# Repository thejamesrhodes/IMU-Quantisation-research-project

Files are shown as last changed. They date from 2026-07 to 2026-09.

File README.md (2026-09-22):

# Sheppard MEMS Rate-Register Quantisation Research Project

Custom STM32F723 hardware, firmware and analysis for measuring output-register
quantisation noise in MEMS rate gyroscopes. Specifically gyroscopes that report an
angular-rate register rather than an integrated angle increment.








*This is a pre-publication research project. The preprint is not yet released.
the results, figures and numbers in this repository are working values and are subject to change. 
Nothing here has been peer-reviewed. Preliminary Datasets are available on Zenodo*

---

## Claim

Rate-register quantisation is predicted to appear at a $-1/2$ Allan-deviation
slope and to be absorbed silently into the fitted angle random walk (ARW),
rather than appearing as the $-1$-slope angle-quantisation ("Q") term of IEEE
Std 952, which describes a different output architecture for angle-increment
parts (FOGs, RLGs). This holds regardless of the error's statistics: whether the
quantisation error is PQN-white, deadbanded, or dithered, it enters the rate
and therefore appears inside the fitted ARW instead of appearing as a separable Q.

If that is correct, fitted stochastic-noise parameters depend on the
configuration (output data rate (ODR), full-scale range (FSR), output word
length) at which they were measured, and the $\sqrt{\text{ODR}}$
bandwidth-transfer rule embedded in every mainstream IMU calibration toolchain,
where it is stated as a condition requiring ideal decimation rather than a
validated result, has never been checked for modern high-ODR consumer parts.

**Why this has gone unnoticed.** The transfer rule was safe for the parts it was
developed on. An MPU-6050-class gyro (≈5 mdps/√Hz, 2011) at ±2000 dps / 100 Hz
sits at a dither ratio $\rho = \sigma/\Delta \approx 0.58$, where the
pseudo-quantisation-noise (PQN) model is valid to ~2 %. The ICM-42688-P
(≈2.8 mdps/√Hz, 2020) sits at $\rho \approx 0.32$, where it is not.

The board is named after W. F. Sheppard, whose 1898 paper gave the $-c^2/12$
correction for the variance of grouped data
([DOI](https://doi.org/10.1112/plms/s1-29.1.353)) - the same $\Delta^2/12$ the
whole experiment turns on. The correction reappears in an unexpected place: the
20-bit reference stream is itself a quantiser, and Sheppard's correction must be
applied to it before it can serve as a reference at all.

---

## Project Goals

- Test whether the fitted stochastic-noise parameters of a MEMS IMU transfer
  across ODR and FSR, and return a single configuration-invariant parameter set
  that does.
- Establish that rate-register quantisation presents at the $-1/2$ slope and is
  absorbed into the fitted ARW, distinct from the IEEE-952 angle-quantisation
  term.
- Derive the exact, parameter-free output-quantisation behaviour, governed by
  two quantities: the dither ratio $\rho = \sigma/\Delta$ and the sub-LSB bias
  phase $\mu \bmod \Delta$. Both measurable from a static code histogram with
  no additional hardware.
- Identify which requantisation architecture the output register implements
  (undithered/PQN, truncation, RPDF- or TPDF-dithered) from output data alone,
  validated against bit-exact software-dithered controls.
- Show that no mainstream toolchain (Kalibr, `allan_variance_ros`, …) models
  output-register quantisation or exposes $\rho$ or $\mu$, and document the
  effect size against configuration so a practitioner can locate their own.
- Publish the hardware, firmware, analysis code and a raw-integer-code,
  temperature-logged dataset. A dataset that, on the searches conducted, does
  not currently exist, because public IMU datasets are distributed as calibrated
  floats and the calibration destroys the code lattice.

---

## Project progress

| Item | Status |
| --- | --- |
| Data-logger PCB (4× IMU) Bring up | ✅ Complete |
| Firmware | ✅ Complete |
| Analysis chain ($\sigma$, $\rho$, $\mu$, $\varphi$, $\eta$; Allan; GMWM) | ✅ Complete |
| Exact $\eta(\rho,\varphi)$ theory, closed form | ✅ Validated |
| Primary curve $\eta(\rho)$ | ✅ Measured over a decade of $\rho$ |
| Experimental results vs exact theory | ✅ 0.4 % of range, no free parameters, both specimens |
| Relevance evidence (toolchain guidance, default ODR/FSR) | 🚧 In progress |
| Manuscript | 🚧 Skeleton, not in this repository |
| Preprint | ⏳ Not yet released |

---

## Hardware

| | |
| --- | --- |
| MCU | STM32F723ZET6, 32 MHz |
| Sensors | 2× ICM-42688-P, 1× ISM330DHCX, 1× BMI323, one SPI bus each |
| Storage | microSD on SDMMC2, exFAT |
| Host link | USB-C on OTG_HS, internal HS PHY |
| Power | 4S NiMH or USB-C |

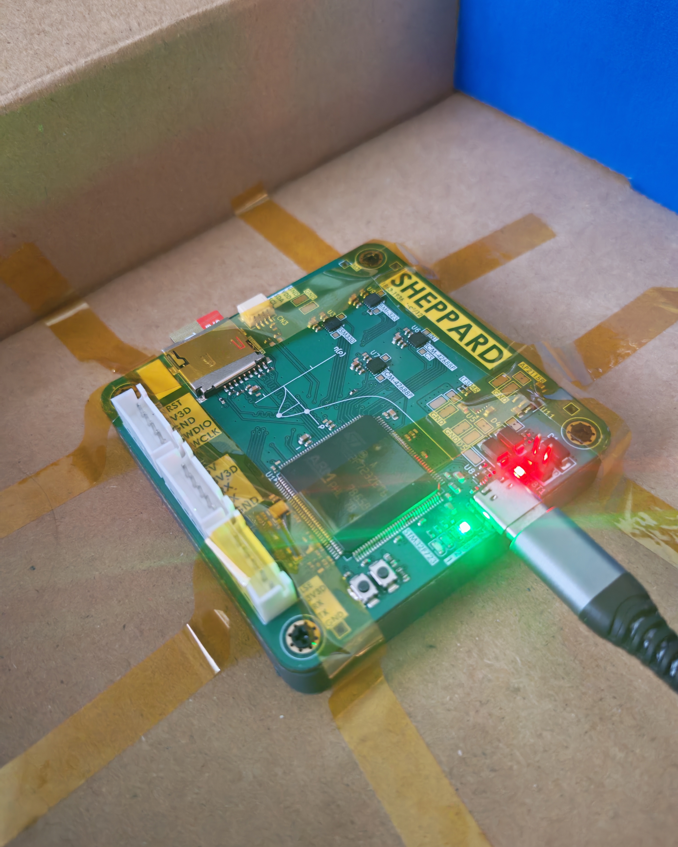
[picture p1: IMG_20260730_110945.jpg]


---

## Repository structure

```
GMWM Software/                 STM32CubeIDE firmware project + host Python
  Core/                          application sources
  tools/                         console, analysis, figures
GMWM Electronics/              KiCad 10 — data-logger PCB
Array Electronics ICM42688P/   KiCad 10 — ICM-42688-P board
Array Software ICM42688P/      firmware for the ICM-42688-P board
Test Datasets/                 records (gitignored; archived to Zenodo)
zenodo/                        dataset deposit build system
```

---

## Running it

```
pip install pyserial numpy matplotlib
python "GMWM Software/tools/sheppard_console.py"
```

The console is a GUI with five tabs: a terminal, the SD-card browser, the
campaign-plan editor, an analysis runner, and a figure viewer that renders the
plots in-app. It finds the board by USB ID rather than COM port and reconnects
on its own when the board resets.

Everything it does is also available from the command line, and the panel prints
the exact command before it runs it, so a result in the GUI and a result in a
terminal are the same result.

```
python analyse.py summary "../../Test Datasets" -o "../../Test Datasets/summary.csv" --fast
python figures.py "../../Test Datasets/summary.csv" -o "../../Figures"
python offset_fit.py "../../Test Datasets" --glob "*ph_k*.sdat"
```

---

## Flashing without an ST-LINK

The board reflashes itself over the same USB-C cable that carries the console.

Run `sheppard_selftest.py` once before trusting the flasher. It feeds the board
bad data five ways and checks each one is refused with flash untouched. Nothing
in it can erase the board.

SWD recovery is always there:

```
STM32_Programmer_CLI -c port=SWD mode=UR -e all -w "Debug/GMWM STM32.elf" -v -rst
```

---

## Status

94 records, two specimens, three axes. The register's architecture is identified
(truncation, bit-exact); $\eta(\rho)$ is measured over a decade of $\rho$; and a
controlled phase sweep tracks the exact theory to **0.4 % of its range with no
free parameters — on both specimens independently**. Repeatability is measured
at $\sigma_\eta = 0.0065$, so the theory is good to about twice the noise floor
of the apparatus.

The manuscript is a skeleton and is not held in this repository. The bench
work the preprint needs is
done; what remains is desk work — the relevance evidence, the software-dither
sweep, and the writing.

---

## Preprint and data

The preprint is not yet released. A manuscript is in preparation and is
intended for submission to a measurement-science journal (IOP
*Measurement Science and Technology*); this section will carry the preprint DOI
when it is public.

Campaign data is archived to Zenodo and is not held in this repository:

> Rhodes, J. (2026). *Paired 16-bit and 19-bit output records from two
> ICM-42688-P MEMS gyroscopes across output-rate and sub-LSB bias-offset
> sweeps* [Data set]. Zenodo. <https://doi.org/10.5281/zenodo.22860515>

---

## Conventions

SI units. LaTeX for maths. Campaign data goes to Zenodo with a DOI, not into
this repository.

The gyroscope's high-resolution FIFO field is 20 bits wide, of which 19 are
significant at ±2000 °/s full scale — the field's least significant bit is
always zero. All resolutions in this repository and in the dataset are quoted
on the 19-bit convention, so the reference lattice step is $\Delta' = \Delta/8$
and the register word is `gyro19 >> 3`.

---

## Licence

MIT — see `LICENSE`. The dataset is licensed separately under CC-BY-4.0.

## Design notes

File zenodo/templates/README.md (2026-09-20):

# Paired 16-bit and 19-bit output records from two ICM-42688-P MEMS gyroscopes across output-rate and sub-LSB bias-offset sweeps

Version {{VERSION}} · built {{BUILT}} · DOI {{DOI}}

{{N_RECORDS}} static-bench records from two ICM-42688-P MEMS gyroscopes (TDK
InvenSense). The sensors were stationary throughout: the board was clamped
and motionless, no rotation was applied, and no motion or attitude ground truth
is included.

Each record captures the device's 16-bit rate register alongside its extended
high-resolution output channel over the same physical samples, so the two
streams are digitisations of one shared input at resolutions differing by a
factor of eight. Samples are stored as raw integer codes with no scaling or
calibration applied, preserving the output code lattice that calibrated
floating-point datasets discard.

Totals: {{N_SAMPLES}} samples, {{HOURS}} hours, three axes per record.

---

## 1. Contents

| File | |
|---|---|
{{INVENTORY}}
| `summary.csv` | {{N_ROWS}} rows — one per record per axis. Configuration and moments only |
| `CODEBOOK.md` | column definitions, closed-form expressions for derived quantities |
| `read_sdat.py` | standalone reader and verifier; standard library + numpy |
| `MANIFEST-SHA256.txt` | SHA-256 of every file, and of every record inside every bundle |
| `LICENSE-DATA.txt` | CC-BY-4.0, covering the records and `summary.csv` |
| `LICENSE-CODE.txt` | MIT, covering `read_sdat.py` |

## 2. Quickstart

```bash
pip install numpy
unzip icm42688p-phase-sweep.zip -d records/

python read_sdat.py verify records              # CRC and continuity, per record
python read_sdat.py info   records/<one>.sdat  # header and achieved rate
python read_sdat.py rate   records/<one>.sdat  # board clock vs sensor clock
python read_sdat.py export records/<one>.sdat -o out.npz
```

`export` writes the decoded integer code arrays `gyro20`, `gyro16`, `accel20`,
`temp_raw`, `tmst_raw`, `tmst_us`, `block_index` and `block_t_us`, together with
`header_json`, so the exported file is self-describing. No scaling is applied.

### Physical units

Three things to get right before scaling the codes.

1. `gyro20` is a 20-bit field of which 19 bits are significant, so
   `sensor.hires_lsb_per_dps` applies to `gyro20 >> 1` and not to `gyro20`.
   Dividing `gyro20` by it directly gives a rate twice too large.
2. `sensor.gyro_lsb_per_dps` and `sensor.hires_lsb_per_dps` are rounded to
   three or four figures, which is a 0.1% scale error. `sensor.delta_mdps` is
   not rounded. Scale from it.
3. `tmst_us` is the sensor's own timestamp counter, which runs about 5% fast
   against the board's crystal-derived timer. Use `odr_measured_hz` from
   `summary.csv` as the sample rate; use `tmst_us` for ordering and gap
   detection only.

```python
import json, numpy as np

z = np.load("out.npz")
D = json.loads(str(z["header_json"]))["sensor"]["delta_mdps"] / 1000   # deg/s

reference_dps = (z["gyro20"] >> 1) * (D / 8)    # 19-bit channel
register_dps  =  z["gyro16"]       *  D         # 16-bit register
```

Both channels are the same physical samples at resolutions differing by a
factor of eight. Their means differ by roughly half a register LSB, which is
the truncation offset and not an error.

### If you only want the derived quantities

`summary.csv` is 47 kB and carries the per-record per-axis moments. The
expressions in `CODEBOOK.md` §3 turn those into sub-code phase, dither ratio,
added power and quantiser gain without downloading any records.

## 3. What is measured

| | |
|---|---|
| Part | ICM-42688-P (TDK InvenSense), two specimens, one SPI bus each |
| Full-scale range | ±2000 °/s — forced by the high-resolution mode |
| Register LSB | Δ = 61.035 m°/s |
| Reference lattice | Δ′ = Δ/8 = 7.629 m°/s |
| Output data rates | 25, 50, 100, 200, 500, 1000, 8000 Hz |
| Anti-alias filter | `585Hz_default` (87 records), `42Hz_floor` (7 records) |
| Logger | STM32F723ZET6, 32 MHz system clock, 8 MHz SPI, microSD |
| Supply | USB, all records |
| Motion | none — stationary, clamped, no applied rotation |
| Orientation | fixed for the whole campaign |

The system clock was held fixed and low across the campaign as an experimental
control so digital switching noise does not couple into the sensor and act as dither.

## 4. Word length and the 19-bit convention

The high-resolution FIFO field is 20 bits wide. Its least significant bit is
zero in all {{N_WORDS}} gyroscope words in this dataset, so 19 bits are
significant and the reachable lattice is Δ/8. Everything here is quoted on the
19-bit convention. The record headers carry `config.word_bits = 20`, which is
the field width, not the significant word length.

The register word is the reference word truncated by three bits,

```
gyro16 == gyro19 >> 3
```

which holds exactly in all {{N_WORDS}} words.

## 5. Characteristics a reuser should know

**Integrity.** All {{N_RECORDS}} records pass block-magic, sequence-continuity,
per-payload CRC-32, packet-header and timestamp-continuity checks. Zero FIFO
overflows and zero buffer-full events across the set.

A spectral line near 119 Hz is present in the records. Its origin has not
been identified. It aliases differently at each output rate, so it appears at a
different frequency and amplitude in each group. Measured, in units of Δ:

| Nominal ODR | Line frequency | Amplitude | Share of variance |
|---|---|---|---|
| 25 Hz | not detected | — | — |
| 50 Hz | 0–17.9 Hz | ≤ 0.07 Δ | 0–6 % |
| 100 Hz | 17.4–18.0 Hz | 0.18–0.24 Δ | 14–23 % |
| 200 Hz | 83.2–84.0 Hz | 0.06–0.76 Δ | 2–62 % |
| 500 Hz | 118.9–119.0 Hz | 0.83–1.15 Δ | 42–63 % |
| 1000 Hz | 118.4–119.4 Hz | 0.09–1.21 Δ | 5–52 % |
| 8000 Hz | 118.9–119.2 Hz | 0.84–1.21 Δ | 23–39 % |

Anyone treating these records as broadband noise should check the spectrum for
their rate first.

**Correlation between samples.** The anti-alias and user filter chains
correlate neighbouring samples at every rate. Estimators assuming independence
will be optimistic.

**Anti-alias filter records.** The seven `42Hz_floor` records vary the filter at
output rates of 50, 200 and 1000 Hz, each paired against default-filter records
at the same rate. Changing that filter also changes the line amplitude above and
the correlation between samples, so the setting is not a clean single-variable
axis. They are included for completeness.

**Temperature.** The die temperature is logged. `temp_span_mK` and
`temp_drift_mK` in `summary.csv` give the excursion and the end-to-end drift
per record; apply whatever criterion suits your purpose.

## 6. Record format

```
offset 0              4096 B  UTF-8 JSON header, space-padded
offset 4096 + 4096k           fixed 4 KiB blocks
  block                       32 B header + 4000 B payload + 64 B pad
```

Payload is the vendor's 20-byte FIFO Packet 4 verbatim (DS-000347 Rev. 1.6
§6.1), CRC-32 over every payload. The JSON header carries the firmware version
and build tag, board UID, clock tree, sensor part and slot, the full sensor
configuration and a verbatim readback of the configuration registers, so each
record is self-describing down to the register contents that produced it.

Filenames are `r<id>_<label>_<odr>.sdat`. `CODEBOOK.md` §4 maps labels to what
was varied.

## 7. Provenance

`summary.csv` is computed from the records in this deposit and from nothing
else. The bundled `read_sdat.py` is the reader used to produce it.

`MANIFEST-SHA256.txt` lists both the files as uploaded and each record inside
each bundle, so an unpacked archive can be checked record by record.

{{HEADER_NOTE}}

## 8. Citation

> Rhodes, J. ({{BUILT}}). *Paired 16-bit and 19-bit output records from two
> ICM-42688-P MEMS gyroscopes across output-rate and sub-LSB bias-offset
> sweeps* (Version {{VERSION}}) [Data set]. Zenodo.
> <https://doi.org/{{DOI}}>

## 9. Licence

Records and `summary.csv`: CC-BY-4.0 (`LICENSE-DATA.txt`).
`read_sdat.py`: MIT (`LICENSE-CODE.txt`).

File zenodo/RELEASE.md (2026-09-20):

# Release and deposit procedure

Version 1.0.0 is published: <https://doi.org/10.5281/zenodo.22860515>
(concept DOI, resolves to the newest version). What follows is the
procedure, and applies unchanged to the next version.

Two separate things, often confused:

| | Where it comes from | What it needs |
|---|---|---|
| **Data DOI** | a manual upload to Zenodo | nothing on GitHub at all |
| **Code DOI** | a GitHub release, archived automatically by Zenodo | a **public** repository |

The data deposit is §2–§4 and can be done today. The code DOI is §5 and is
blocked until §0 is resolved.

---

## 0. Read this first

**`.gitignore` stops future commits. It does not remove anything already in the
repository's history.** Seven commits in this repository add or modify the
technical notes, and the manuscript tree is tracked as well. Anyone with read
access can recover all of it with

```
git log --all --diff-filter=A --name-only
git show <commit>:<path>
```

Zenodo's GitHub integration [can only access public repositories][zgh]. So a
code DOI by that route means making this repository public, and making *this*
repository public publishes the history.

Three ways out, in the order I would consider them.

### A. Keep this repository private; upload the data deposit by hand

Nothing about history needs to change, because the data deposit never touches
GitHub. This is the whole of §2–§4 and it is sufficient for everything the
dataset is for — the DOI, the citation, the CV entry.

Cost: no code DOI yet. That can be added at any time, and adding it later does
not affect the data DOI.

### B. Publish a clean repository with no history

Export the working tree, drop the internal files, and initialise a new
repository from it. The current repository stays private and keeps being the
working one.

```powershell
cd "C:\"
git clone --depth 1 "file:///C:/IMU Research Project" IMU-release
cd IMU-release
Remove-Item -Recurse -Force .git
Remove-Item -Recurse -Force paper, Misc, "Test Datasets", Figures -EA SilentlyContinue
Remove-Item TN-*.md, SUPERSEDED.md, SESSION_HANDOVER.md, *_AUDIT_*.md, `
            Table_Verification_*.md, Concept_Note*.md, Preprint_Scaffold*.md, `
            DOCUMENTS_TO_ADD_TO_PROJECT.md, ZENODO_DEPOSIT_PLAN.md -EA SilentlyContinue
git init -b main
git add .
git commit -m "Initial public release: firmware, analysis tools, hardware, deposit build"
```

Then create an empty repository on GitHub and push to it. **Check the file list
before the first push** — once it is public, it is public:

```powershell
git ls-files | Select-String -Pattern "TN-|SUPERSEDED|AUDIT|Concept_Note|paper/|Test Datasets"
# expect: no output
```

### C. Rewrite this repository's history

`git filter-repo --path-glob 'TN-*.md' --invert-paths` and similar, then force
push. It works, but every existing clone and fork keeps the old objects, and if
the repository has ever been public you should assume the notes are already
copied. B is less work and has no failure mode.

**Check the current visibility before deciding.** GitHub → the repository →
Settings → General → Danger Zone shows whether it is public or private.

[zgh]: https://help.zenodo.org/docs/github/enable-repository/

### Before any of them: know what is in the source comments

The firmware and the analysis tools cite the project's own notes by number in
their comments. `.gitignore` does nothing about that, because the citations are
inside files that *should* be published.

```powershell
cd "C:\IMU Research Project\zenodo"
python check_public.py
python check_public.py --detail    # file:line for every hit
```

None of them disclose a result — they disclose that an internal numbering
scheme exists. Whether that is acceptable is a judgement. The script reports
and does not rewrite, because a blind regex pass over source comments is a good
way to damage working code for nothing. If you decide to strip them, do it in
the export of route B and keep the working tree intact.

The data deposit is unaffected either way: `build_deposit.py` scrubs the reader
it ships and fails the build if anything survives.

---

## 1. Untrack the internal files

Do this whichever route you take. It changes what future commits contain.

```powershell
cd "C:\IMU Research Project"
git rm -r --cached . --quiet
git add .
git status --short
```

`git status` should now show the internal files as deleted from the index while
they remain on disk. Confirm before committing:

```powershell
git status --short | Select-String -Pattern "^D " | Measure-Object
git ls-files | Select-String -Pattern "TN-|SUPERSEDED|AUDIT|paper/"   # expect none
git commit -m "Untrack internal notes, manuscript and generated figures"
```

---

## 2. Build the deposit

```powershell
cd "C:\IMU Research Project\zenodo"
python build_deposit.py --records "..\Test Datasets" --out build
```

The build refuses to finish if any record fails verification, if the 19-bit
relation does not hold in every word, or if any internal reference survives
into a deposit text file. Expected output: 11 files, about 100 MB.

To reserve the DOI first (§4 step 2) and have it appear inside the README,
codebook, licence and citation, rebuild with it:

```powershell
python build_deposit.py --records "..\Test Datasets" --out build `
                        --doi "10.5281/zenodo.22860516" --version 1.0.0
```

`--keep-gate-rule` ships the record headers exactly as logged, including the
internal name of the thermal criterion in `gate.rule`. Default is to normalise
it; see §3 of the deposit's own `README.md`.

---

## 3. Check it before uploading

```powershell
cd build
python read_sdat.py verify (Get-ChildItem -Recurse -Filter *.sdat).FullName
```

That needs the bundles unpacked first. The complete check, from an empty
directory, is the one that matters — it proves the deposit stands alone:

```powershell
$t = "$env:TEMP\deposit-check"
Remove-Item -Recurse -Force $t -EA SilentlyContinue
New-Item -ItemType Directory $t | Out-Null
Copy-Item build\* $t
cd $t
Get-ChildItem *.zip | ForEach-Object { Expand-Archive $_ -DestinationPath records -Force }
python read_sdat.py verify (Get-ChildItem records -Filter *.sdat).FullName | Select-String "^FAIL"
# expect: no output
```

Then confirm the manifest:

```powershell
Get-Content MANIFEST-SHA256.txt |
  Where-Object { $_ -match "^[0-9a-f]{64}  \w[-\w]*\.zip::" } |
  ForEach-Object {
    $h, $n = $_ -split "  ", 2
    $f = "records\" + ($n -split "::")[1]
    if ((Get-FileHash $f -Algorithm SHA256).Hash -ne $h.ToUpper()) { "MISMATCH $f" }
  }
# expect: no output
```

---

## 4. Upload to Zenodo

1. Sign in at <https://zenodo.org>. Add an ORCID first if you do not have one —
   it takes ten minutes, it is free, and a deposit without one is materially
   weaker. Link it under Profile → Linked accounts.

2. **New upload** → **Get a DOI now!** to reserve the DOI. Do not delete the
   draft afterwards; the reservation is lost with it.

3. Rebuild with the reserved DOI (§2) so it appears in the README, codebook and
   citation, then upload all 11 files from `build\`.

4. Metadata:

   | Field | Value |
   |---|---|
   | Resource type | Dataset |
   | Title | Paired 16-bit and 19-bit output records from two ICM-42688-P MEMS gyroscopes across output-rate and sub-LSB bias-offset sweeps |
   | Creators | Rhodes, James — *Independent Researcher* — ORCID 0009-0000-9893-145X |
   | Description, copyright, references, keywords | see `ZENODO_METADATA.md`, paste-ready |
   | Licences | Creative Commons Attribution 4.0 International **and** MIT |
   | Version | 1.0.0 |
   | Language | English |
   | Keywords | MEMS gyroscope; quantisation noise; Allan variance; angle random walk; inertial sensor calibration; ICM-42688-P; truncating quantiser; sensor characterisation |

   Leave *Related identifiers* empty for now. Metadata stays editable forever,
   so the manuscript link can be added when there is one.

5. **Preview**, read it as a stranger, then **Publish**.

**Files are editable for 45 days after publishing. Metadata is editable
indefinitely.** So a metadata gap is cheap and a file mistake is not. After 45
days a file change means a new version with its own DOI.

---

## 5. Code DOI, later

Only after §0 is resolved and a public repository exists.

1. Zenodo → Profile → Linked accounts → connect GitHub.
2. Zenodo → GitHub → toggle the repository **On**.
3. On GitHub, draft a release and tag it:

```powershell
git tag -a v1.0.0 -m "Firmware, analysis tools and hardware as used for the dataset"
git push origin v1.0.0
```

4. Publish the release on GitHub. Zenodo ingests it and issues a DOI.
5. Edit the **data** deposit's metadata and add the code DOI under
   *Related identifiers* → `isSupplementedBy`. Add the reverse link on the code
   record.

---

## 6. After publishing

- Put the **concept** DOI on the CV and in the manuscript, not the version DOI.
  The concept DOI always resolves to the newest version; the version DOI pins
  one release.
- Fill the manuscript's data-availability statement with the concept DOI and
  the repository URL.
- New records later — the remaining run plan, a second campaign — are a **new
  version** of the same deposit, not a new record. Rebuild with
  `--version 1.1.0` and use *New version* on the Zenodo record.

---

## What the build produces

| File | |
|---|---|
| `sheppard-phase-sweep.zip` | 50 records |
| `sheppard-odr-sweep.zip` | 14 records |
| `sheppard-offset-calibration.zip` | 22 records |
| `sheppard-aaf-variation.zip` | 8 records |
| `summary.csv` | 282 rows, 22 columns |
| `read_sdat.py` | standalone reader |
| `CODEBOOK.md` | column definitions and derived quantities |
| `README.md` | deposit-level documentation |
| `MANIFEST-SHA256.txt` | hashes, including per-record inside each bundle |
| `LICENSE-DATA.txt` | CC-BY-4.0 |
| `LICENSE-CODE.txt` | MIT |

11 files, about 100 MB. Zenodo allows 100 files and 50 GB per record.

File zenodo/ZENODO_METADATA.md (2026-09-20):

# Zenodo metadata — paste-ready

DOI reserved: **10.5281/zenodo.22860516**

Everything below goes into the Zenodo deposit form. Fields marked **required**
are the ones with a red star.

---

## Resource type **required**

`Dataset`

---

## Title **required**

```
Paired 16-bit and 19-bit output records from two ICM-42688-P MEMS gyroscopes across output-rate and sub-LSB bias-offset sweeps
```

17 words, 124 characters.

---

## Creators **required**

| Field | Value |
|---|---|
| Family name | `Rhodes` |
| Given names | `James` |
| Identifier | your ORCID |
| Affiliation | `Independent researcher` |
| Role | leave blank |

---

## Publication date **required**

Today's date. Zenodo prefills it.

---

## Description **required**

Zenodo's description box is rich text. Paste this. 279 words, inside the 120-280
typical of Zenodo dataset records.

```
This dataset contains 94 static-bench records from two ICM-42688-P MEMS
gyroscopes (TDK InvenSense). The sensors were stationary throughout: the board
was clamped and motionless, no rotation was applied, and no motion or attitude
ground truth is included.

Each record captures the device's 16-bit rate register alongside its extended
high-resolution output channel over the same physical samples, so the two
streams are digitisations of one shared input at resolutions differing by a
factor of eight. Samples are stored as raw integer codes, with no scaling or
calibration applied, preserving the output code lattice that calibrated
floating-point datasets discard. Totals: 10,599,722 samples, 9.43 hours, three
axes per record.

Two quantities were varied, on independent axes rather than as a grid: the
output data rate (25 Hz to 8 kHz), and the device's user-offset trim register,
which moves the sensor bias within a single output code.

Contents: four record bundles (offset sweep, output-rate sweep, trim-register
calibration, anti-alias filter variation); summary.csv, giving per-record
per-axis configuration and moments; a standalone Python reader and verifier; a
codebook defining every column and giving closed-form expressions for derived
quantities; and a SHA-256 manifest.

Format: each record carries a 4 KiB JSON header with firmware version, clock
and sensor configuration and a verbatim configuration-register readback,
followed by 4 KiB data blocks holding the vendor's FIFO packets with CRC-32
over every payload. All 94 records pass integrity verification.

Notes: a spectral line near 119 Hz is present and aliases to a different
frequency at each output rate; measured amplitudes are tabulated in README.md.
The filter chains correlate neighbouring samples at every rate. Die
temperature is logged per record.

Licence: records and summary.csv are CC-BY-4.0; the bundled reader is MIT.
```

---

## Licences **required** — add both

Zenodo supports several licences on one record, and documents exactly this case
("software under the MIT license, but documentation under CC-BY"). This deposit
is mixed, so declare both rather than picking one:

| Licence | Covers |
|---|---|
| `Creative Commons Attribution 4.0 International` | the record bundles and `summary.csv` |
| `MIT License` | `read_sdat.py` |

CC-BY-4.0 is Zenodo's default and is already selected. Click **Edit** beside it
to confirm, then **Add standard** and search `MIT` for the second. Zenodo uses
the SPDX list, so the entries are `cc-by-4.0` and `mit`.

Watch for near-identical entries in the picker — several Creative Commons
variants differ only by version or by `-NC` / `-SA` suffixes.

---

## Copyright

Optional free-text field, separate from the licence. It names the rights
holder; the licence says what others may do. Worth filling here precisely
because the deposit is mixed-licence — one unambiguous statement of who holds
the rights removes any question about which file belongs to whom.

```
Copyright (c) 2026 James Rhodes. Records and summary.csv licensed CC-BY-4.0; read_sdat.py licensed MIT.
```

---

## References

Optional list of free-text references, rendered as a References block on the
record page. Add one per entry.

These are exactly the five cited in `CODEBOOK.md` — the datasheet defines the
packet structure and register names, and the other four define the quantiser
relations used in §3. Nothing is listed that the deposit does not use. All
DOIs verified against Crossref.

```
TDK InvenSense (2020). ICM-42688-P Datasheet, DS-000347 Rev. 1.6.
```

```
Sheppard, W. F. (1898). On the Calculation of the most Probable Values of Frequency-Constants, for Data arranged according to Equidistant Divisions of a Scale. Proceedings of the London Mathematical Society, s1-29, 353-380. https://doi.org/10.1112/plms/s1-29.1.353
```

```
Sripad, A., & Snyder, D. (1977). A Necessary and Sufficient Condition for Quantization Errors to be Uniform and White. IEEE Transactions on Acoustics, Speech, and Signal Processing, 25(5), 442-448. https://doi.org/10.1109/TASSP.1977.1162977
```

```
Widrow, B., & Kollar, I. (2008). Quantization Noise: Roundoff Error in Digital Computation, Signal Processing, Control, and Communications. Cambridge University Press. https://doi.org/10.1017/CBO9780511754661
```

```
Vardeman, S. B. (2005). Sheppard's Correction for Variances and the "Quantization Noise Model". IEEE Transactions on Instrumentation and Measurement, 54(5), 2117-2119. https://doi.org/10.1109/TIM.2005.853348
```

**Not included: IEEE Std 952.** It was in an earlier draft of the codebook and
is now removed from both. It specifies test procedures for interferometric
fibre-optic gyroscopes — a different output architecture from the part in this
dataset — and nothing in the deposit uses it. Listing it would suggest the
records relate to that standard.

---

## Version

```
1.0.0
```

---

## Language

```
English
```

---

## Keywords

Data-descriptive terms first, so the deposit is findable by people who are not
already thinking about quantisation. Add one at a time:

```
MEMS gyroscope
inertial measurement unit
raw sensor data
uncalibrated data
static bench measurement
ICM-42688-P
sensor characterisation
Allan variance
output data rate
quantisation noise
angle random walk
truncating quantiser
```

---

## Related works

Leave empty for now. Metadata stays editable indefinitely, so the manuscript
and the code repository go in later:

| Relation | Identifier | Resource type |
|---|---|---|
| `is supplemented by` | repository URL | Software |
| `is supplement to` | manuscript DOI, once it has one | Publication |

---

## Files

All eleven files from `zenodo\build\`:

```
CODEBOOK.md
LICENSE-CODE.txt
LICENSE-DATA.txt
MANIFEST-SHA256.txt
README.md
icm42688p-aaf-variation.zip
icm42688p-odr-sweep.zip
icm42688p-offset-calibration.zip
icm42688p-phase-sweep.zip
read_sdat.py
summary.csv
```

Set the default preview file to `README.md` if Zenodo offers the choice.

---

## Visibility

`Public`. Do not tick "Apply an embargo".

---

## Citation this produces

> Rhodes, J. (2026). *Paired 16-bit and 19-bit output records from two
> ICM-42688-P MEMS gyroscopes across output-rate and sub-LSB bias-offset
> sweeps* (Version 1.0.0) [Data set]. Zenodo.
> <https://doi.org/10.5281/zenodo.22860516>

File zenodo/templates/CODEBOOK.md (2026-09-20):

# Codebook

Version {{VERSION}} · built {{BUILT}} · DOI {{DOI}}

`summary.csv` has {{N_ROWS}} rows, one per record per gyroscope axis, and
{{N_RECORDS}} distinct records, all taken with the sensors stationary. Every
column is either configuration read from the record header or a moment computed
from that record's own samples. No column is fitted, corrected toward a model,
or compared against a prediction.

Quantities derived from these columns are given in §3 as explicit expressions,
so that a reader applies them rather than inheriting them.

Formulas are written in plain text and are directly usable in Python or any
spreadsheet. `mod` is the non-negative remainder, `sqrt` the square root,
`floor` rounding toward negative infinity, and `^` exponentiation.

---

## 1. Conventions

| Symbol | Definition | Value |
|---|---|---|
| Δ | 16-bit rate-register LSB | 61.035 m°/s at ±2000 °/s |
| Δ′ | reference-lattice step | Δ/8 = 7.629 m°/s |
| v | continuous rate at the quantiser input | — |
| x | reference stream, 19-bit | in units of Δ |
| Q | register stream, 16-bit | in units of Δ |
| φ | sub-code bias phase | in units of Δ |
| ρ | dither ratio | dimensionless |
| η | normalised added power | dimensionless |
| G | quantiser gain | dimensionless |

All `*_lsb` and `*_lsb2` columns are in units of Δ and Δ² respectively. To
convert to physical units multiply by Δ or Δ²; `sensor.delta_mdps` in each
record header carries the value that record was taken at.

**Word length.** The device's high-resolution FIFO field is 20 bits wide. The
field's least significant bit is zero in all {{N_WORDS}} gyroscope words in this
dataset, so 19 bits are significant and the reachable lattice is Δ/8. All
resolutions here are quoted on the 19-bit convention:

```
x  = Δ' * gyro19          with Δ' = Δ/8
gyro16 = gyro19 >> 3
```

The second identity holds bit-exactly in all {{N_WORDS}} words, so the register
is a truncation of the reference and not a rounding of it:

```
Q(v) = Δ * floor(v / Δ)
```

**Phase reference.** φ is edge-referenced: φ = 0 at a code boundary,
φ = 0.5 at mid-code.

**Detrending.** Every moment column is computed on the record after removal of
a least-squares straight line, so that bench temperature drift during a record
does not enter the variance. The first-moment column `mean_ref_lsb` is computed
on the undetrended stream.

---

## 2. Columns

### 2.1 Identity

| Column | Definition |
|---|---|
| `file` | record filename |
| `label` | run label from the record header |
| `specimen` | sensor slot, 1 or 2; distinct physical parts of the same type |
| `axis` | `X`, `Y` or `Z` |

### 2.2 Configuration, read verbatim from the record header

| Column | Definition | Units |
|---|---|---|
| `odr_nominal_hz` | commanded output data rate | Hz |
| `odr_measured_hz` | rate measured by the logger's own timer over the record | Hz |
| `aaf` | anti-alias filter setting | — |
| `offset_user_steps` | value written to the device's user-offset trim register | steps |
| `power` | supply during the record | — |

### 2.3 Extent and integrity

| Column | Definition |
|---|---|
| `n_samples` | FIFO samples in the record |
| `minutes` | `n_samples / odr_measured_hz / 60` |
| `verify` | `ok` if block magic, sequence continuity, CRC-32 over every payload, packet-header sanity and timestamp continuity all pass |
| `fifo_overflows` | device-reported FIFO overflow count |
| `ring_full` | logger-reported buffer-full count |
| `temp_span_mK` | `1000 * (max(T) - min(T))` over the record, from the device's own die sensor |
| `temp_drift_mK` | `1000 * abs(mean(T, last 5%) - mean(T, first 5%))` |

`verify` is `ok` for every row in this release.

### 2.4 Moments

`Var` and `Cov` are sample estimators with denominator `n - 1`. A tilde denotes
the detrended stream.

| Column | Definition |
|---|---|
| `mean_ref_lsb` | `mean(x)`, undetrended |
| `var_ref_lsb2` | `Var(x~)` |
| `var_reg_lsb2` | `Var(Q~)` |
| `cov_lsb2` | `Cov(Q~, x~)` |

### 2.5 Descriptive

| Column | Definition |
|---|---|
| `tail_ratio` | `std(x~) / (1.4826 * MAD(x~))`. The constant is the Gaussian consistency factor. Values materially above 1 indicate the tails carry disproportionate weight — a transient during the record rather than wide noise. |
| `n_codes` | distinct 16-bit register codes occupied by the axis over the record |

---

## 3. Derived quantities

Each expression is exact given the definitions in §1 and the model of the
reference channel in §3.1. Nine significant figures are carried in the moment
columns so that these reproduce to more places than are useful.

### 3.1 The reference channel is itself a quantiser

x is not v. It is v truncated onto the Δ′ lattice. Where the input is well
dithered relative to the step - Sripad and Snyder (1977) give the necessary and
sufficient condition - the first two moments of a truncating quantiser of step
s relate to those of its input as [Sheppard 1898; Widrow & Kollár 2008, ch. 4]:

```
mean(x) = mean(v) - Δ'/2
Var(x)  = Var(v)  + Δ'^2 / 12
```

Vardeman (2005) sets out the relationship between Sheppard's correction and
the quantisation-noise model directly.

With Δ′ = Δ/8, in units of Δ:

```
Δ'/2     = 1/16  = 0.0625
Δ'^2/12  = 1/768 = 0.00130208333
```

### 3.2 Sub-code phase

```
phi = (mean_ref_lsb + 1/16) mod 1
```

Without the `1/16` the result is the phase of the reference lattice rather
than of the continuous input.

### 3.3 Dither ratio

```
rho = sqrt(var_ref_lsb2 - 1/768)
```

This is the standard deviation of v in units of Δ.

### 3.4 Added power

Normalised by the ideal quantiser variance Δ²/12:

```
eta = 12 * (var_reg_lsb2 - var_ref_lsb2) + 1/64
```

equivalently `(Var(Q) - Var(v)) / (Δ^2 / 12)`.

`eta = 1` recovers the classical additive model, in which the quantiser adds
Δ²/12 [Widrow & Kollár 2008, ch. 4]. `eta = 0` does not.

### 3.5 Gain

```
G = cov_lsb2 / (var_ref_lsb2 - 1/768)
```

equivalently `Cov(Q, v) / Var(v)`.

This uses `Cov(Q, x)` in place of `Cov(Q, v)`, which neglects `Cov(Q, x - v)`.
The reference lattice is eight times finer than the register, so on these
records the reference channel's own error is uncorrelated with the input to
well below the precision carried here.

### 3.6 Worked example

Taking row 1 of `summary.csv` and working in units of Δ:

```python
import csv

r  = next(csv.DictReader(open("summary.csv")))
m  = float(r["mean_ref_lsb"])
vx = float(r["var_ref_lsb2"])
vq = float(r["var_reg_lsb2"])
cv = float(r["cov_lsb2"])

phi = (m + 1/16) % 1
rho = (vx - 1/768) ** 0.5
eta = 12 * (vq - vx) + 1/64
G   = cv / (vx - 1/768)
```

---

## 4. Record families

Record filenames are `r<id>_<label>_<odr>.sdat`. Labels group as follows.

| Prefix or suffix | Bundle | What was varied |
|---|---|---|
| `ph_k`, `s2ph_k`, `c1_k`, `s1rep_k` | phase-sweep | `offset_user_steps`, at fixed rate and filter |
| `*_odr*` | odr-sweep | output data rate |
| `off*`, `c2_*`, `p2cal_*` | offset-calibration | `offset_user_steps` in ladders, for trim-register characterisation |
| `aaf*`, `*_fl` | aaf-variation | anti-alias filter, at 50, 200 and 1000 Hz |

The `*_fl` records vary the anti-alias filter at output rates of 50, 200 and
1000 Hz, each paired against default-filter records at the same rate. Changing
that filter also changes the amplitude of the spectral line described in
`README.md` §5 and alters the correlation between successive samples, so the
setting is not a clean single-variable axis. They are included for
completeness.

---

## 5. Record header fields

Each `.sdat` file opens with a 4 KiB UTF-8 JSON header. `read_sdat.py info`
prints it. Register names and the FIFO packet layout follow the device
datasheet (TDK InvenSense DS-000347 Rev. 1.6). Fields of note:

| Path | Meaning |
|---|---|
| `sensor.delta_mdps` | Δ in m°/s for that record |
| `sensor.hires_lsb_per_dps` | reference-channel scale, `1/Δ'` |
| `config.word_bits` | the FIFO field width, 20. See §1 on the 19-bit convention |
| `config.offset_user_steps` | trim-register value |
| `registers_readback` | verbatim configuration-register contents |
| `fw.version`, `fw.tag`, `fw.built` | logger firmware provenance |
| `clock.sysclk_hz` | logger system clock, held fixed as an experimental control |

---

## 6. References

- Sheppard, W. F., 'On the Calculation of the most Probable Values of
  Frequency-Constants, for Data arranged according to Equidistant Divisions of
  a Scale', *Proceedings of the London Mathematical Society*, s1-29 (1898),
  353–380 <https://doi.org/10.1112/plms/s1-29.1.353>
- Sripad, A., and D. Snyder, 'A Necessary and Sufficient Condition for
  Quantization Errors to be Uniform and White', *IEEE Transactions on
  Acoustics, Speech, and Signal Processing*, 25 (1977), 442–448
  <https://doi.org/10.1109/TASSP.1977.1162977>
- Widrow, B., and I. Kollár, *Quantization Noise: Roundoff Error in Digital
  Computation, Signal Processing, Control, and Communications* (Cambridge
  University Press, 2008) <https://doi.org/10.1017/CBO9780511754661>
- Vardeman, S. B., 'Sheppard's Correction for Variances and the "Quantization
  Noise Model"', *IEEE Transactions on Instrumentation and Measurement*, 54
  (2005), 2117–2119 <https://doi.org/10.1109/TIM.2005.853348>
- TDK InvenSense, *ICM-42688-P Datasheet*, DS-000347 Rev. 1.6 — FIFO packet
  structure (§6.1), register map, temperature scaling

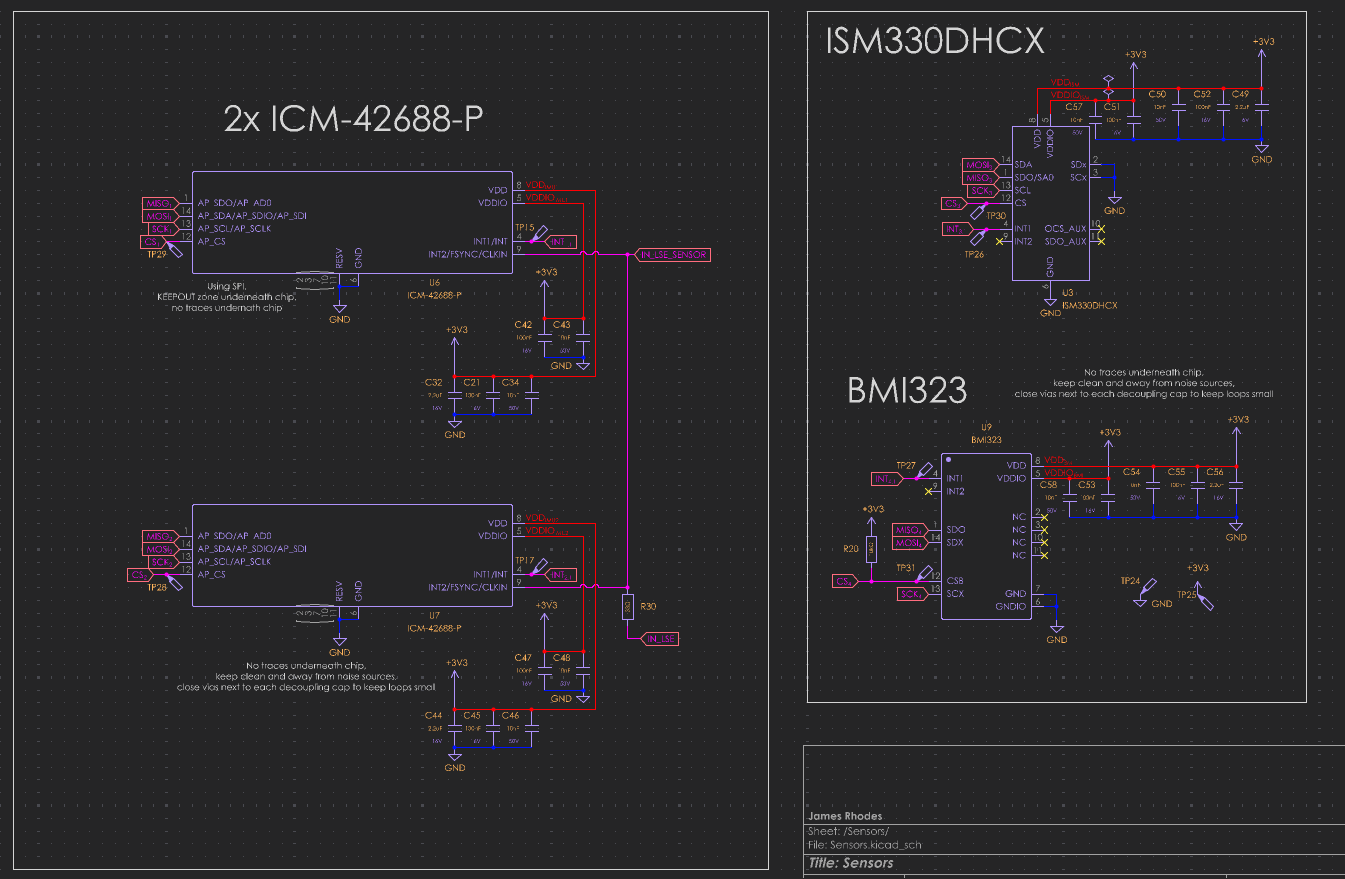
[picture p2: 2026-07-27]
GMWM Electronics/Board Documentation Images/KiCad Screenshots/Dark/Screenshot 2026-07-16 204811.png

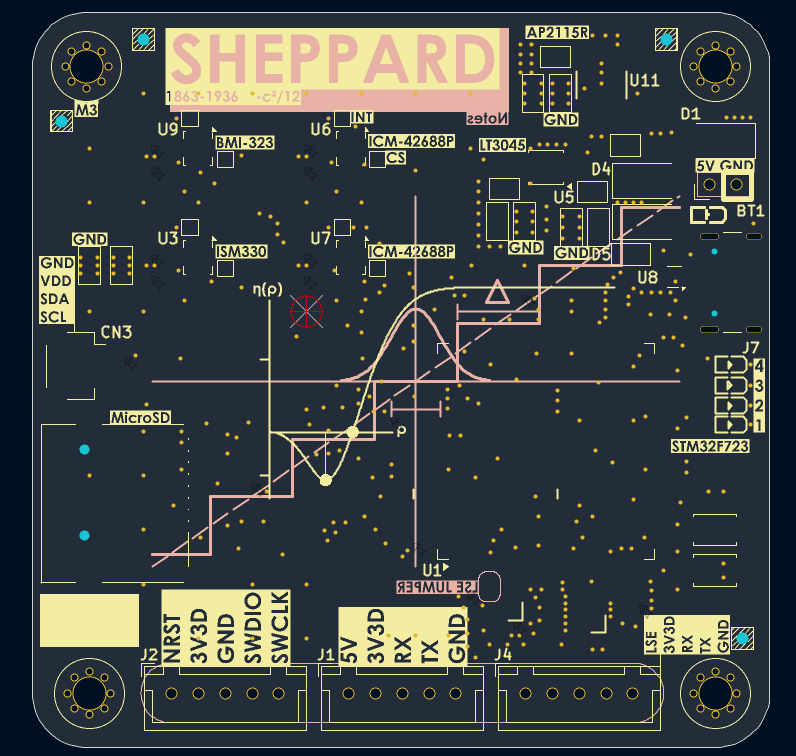
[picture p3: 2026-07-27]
GMWM Electronics/Board Documentation Images/KiCad Screenshots/Light/Screenshot 2026-07-16 204743.png

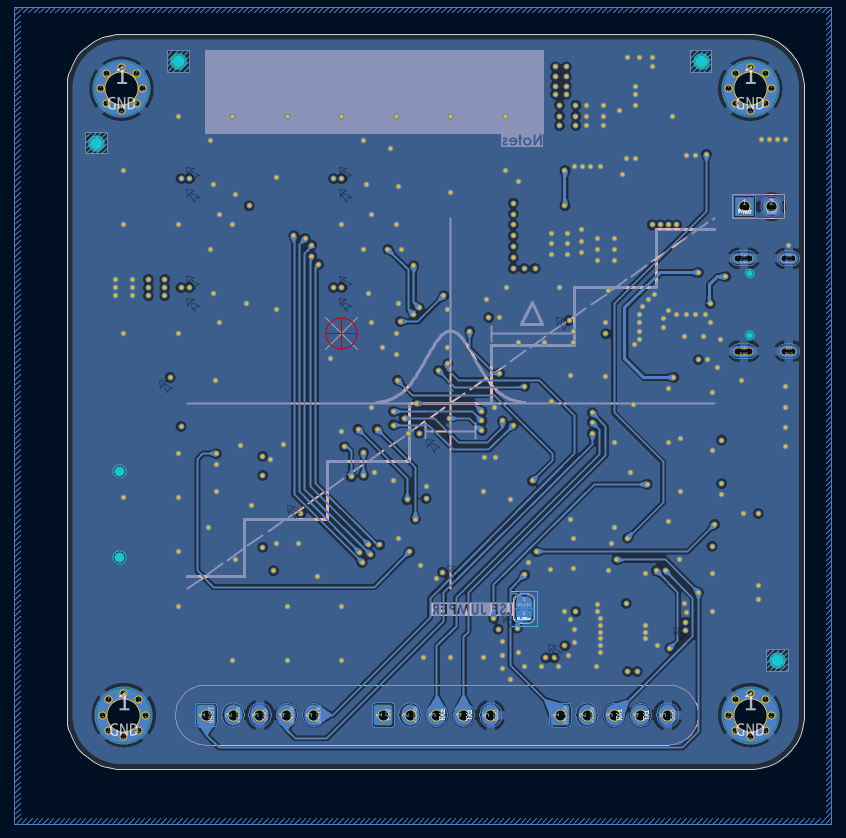
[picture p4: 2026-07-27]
GMWM Electronics/Board Documentation Images/KiCad Screenshots/Dark/Screenshot 2026-07-16 204545.png

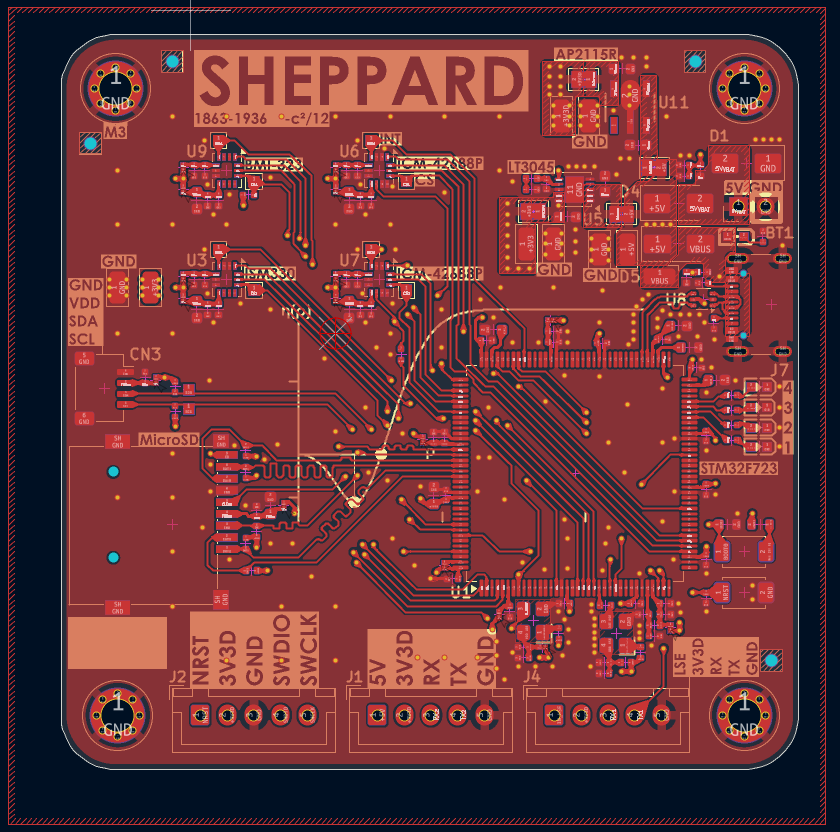
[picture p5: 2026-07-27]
GMWM Electronics/Board Documentation Images/KiCad Screenshots/Dark/Screenshot 2026-07-16 204449.png

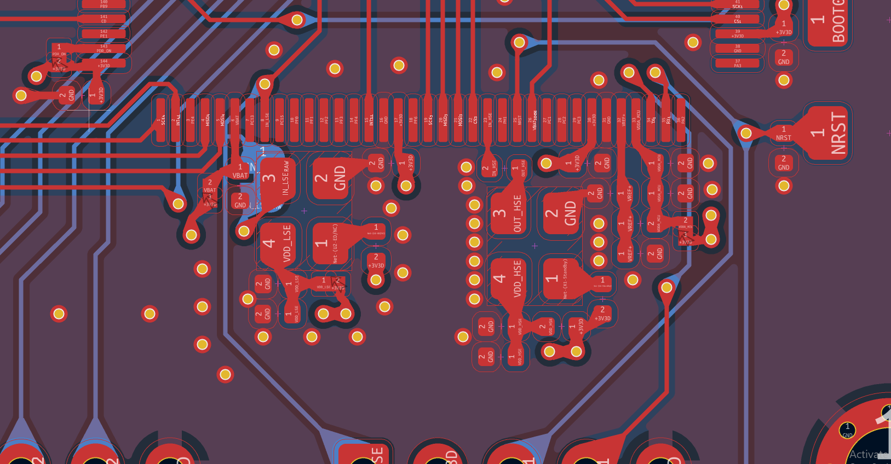
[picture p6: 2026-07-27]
GMWM Electronics/Board Documentation Images/KiCad Screenshots/Dark/Screenshot 2026-07-16 204658.png

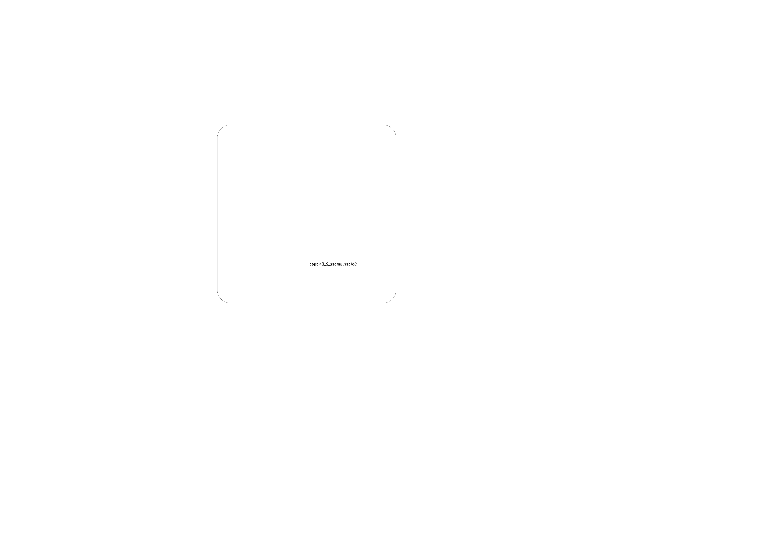
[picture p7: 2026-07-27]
GMWM Electronics/Board Documentation Images/Black and White Layers/GMWM Analysis Board-B_Fab.png

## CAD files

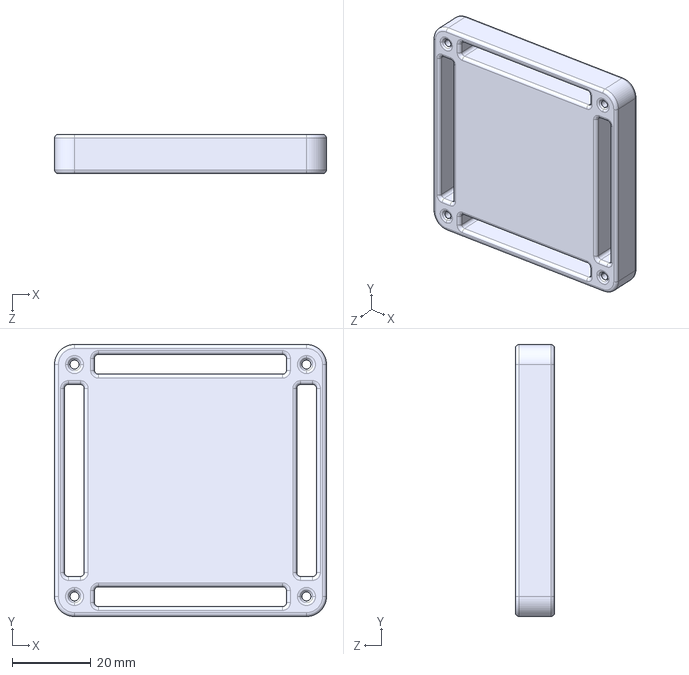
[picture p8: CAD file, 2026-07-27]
GMWM Electronics/Board Mounting Hardware/Printed_Mounting_Stand_V1.0.STEP
69.0 x 69.0 x 10.0 mm

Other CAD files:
GMWM Electronics/Board Mounting Hardware/Printed_Mounting_Stand_V1.0.3mf
GMWM Electronics/Board Mounting Hardware/Printed_Mounting_Stand_V1.0.SLDPRT

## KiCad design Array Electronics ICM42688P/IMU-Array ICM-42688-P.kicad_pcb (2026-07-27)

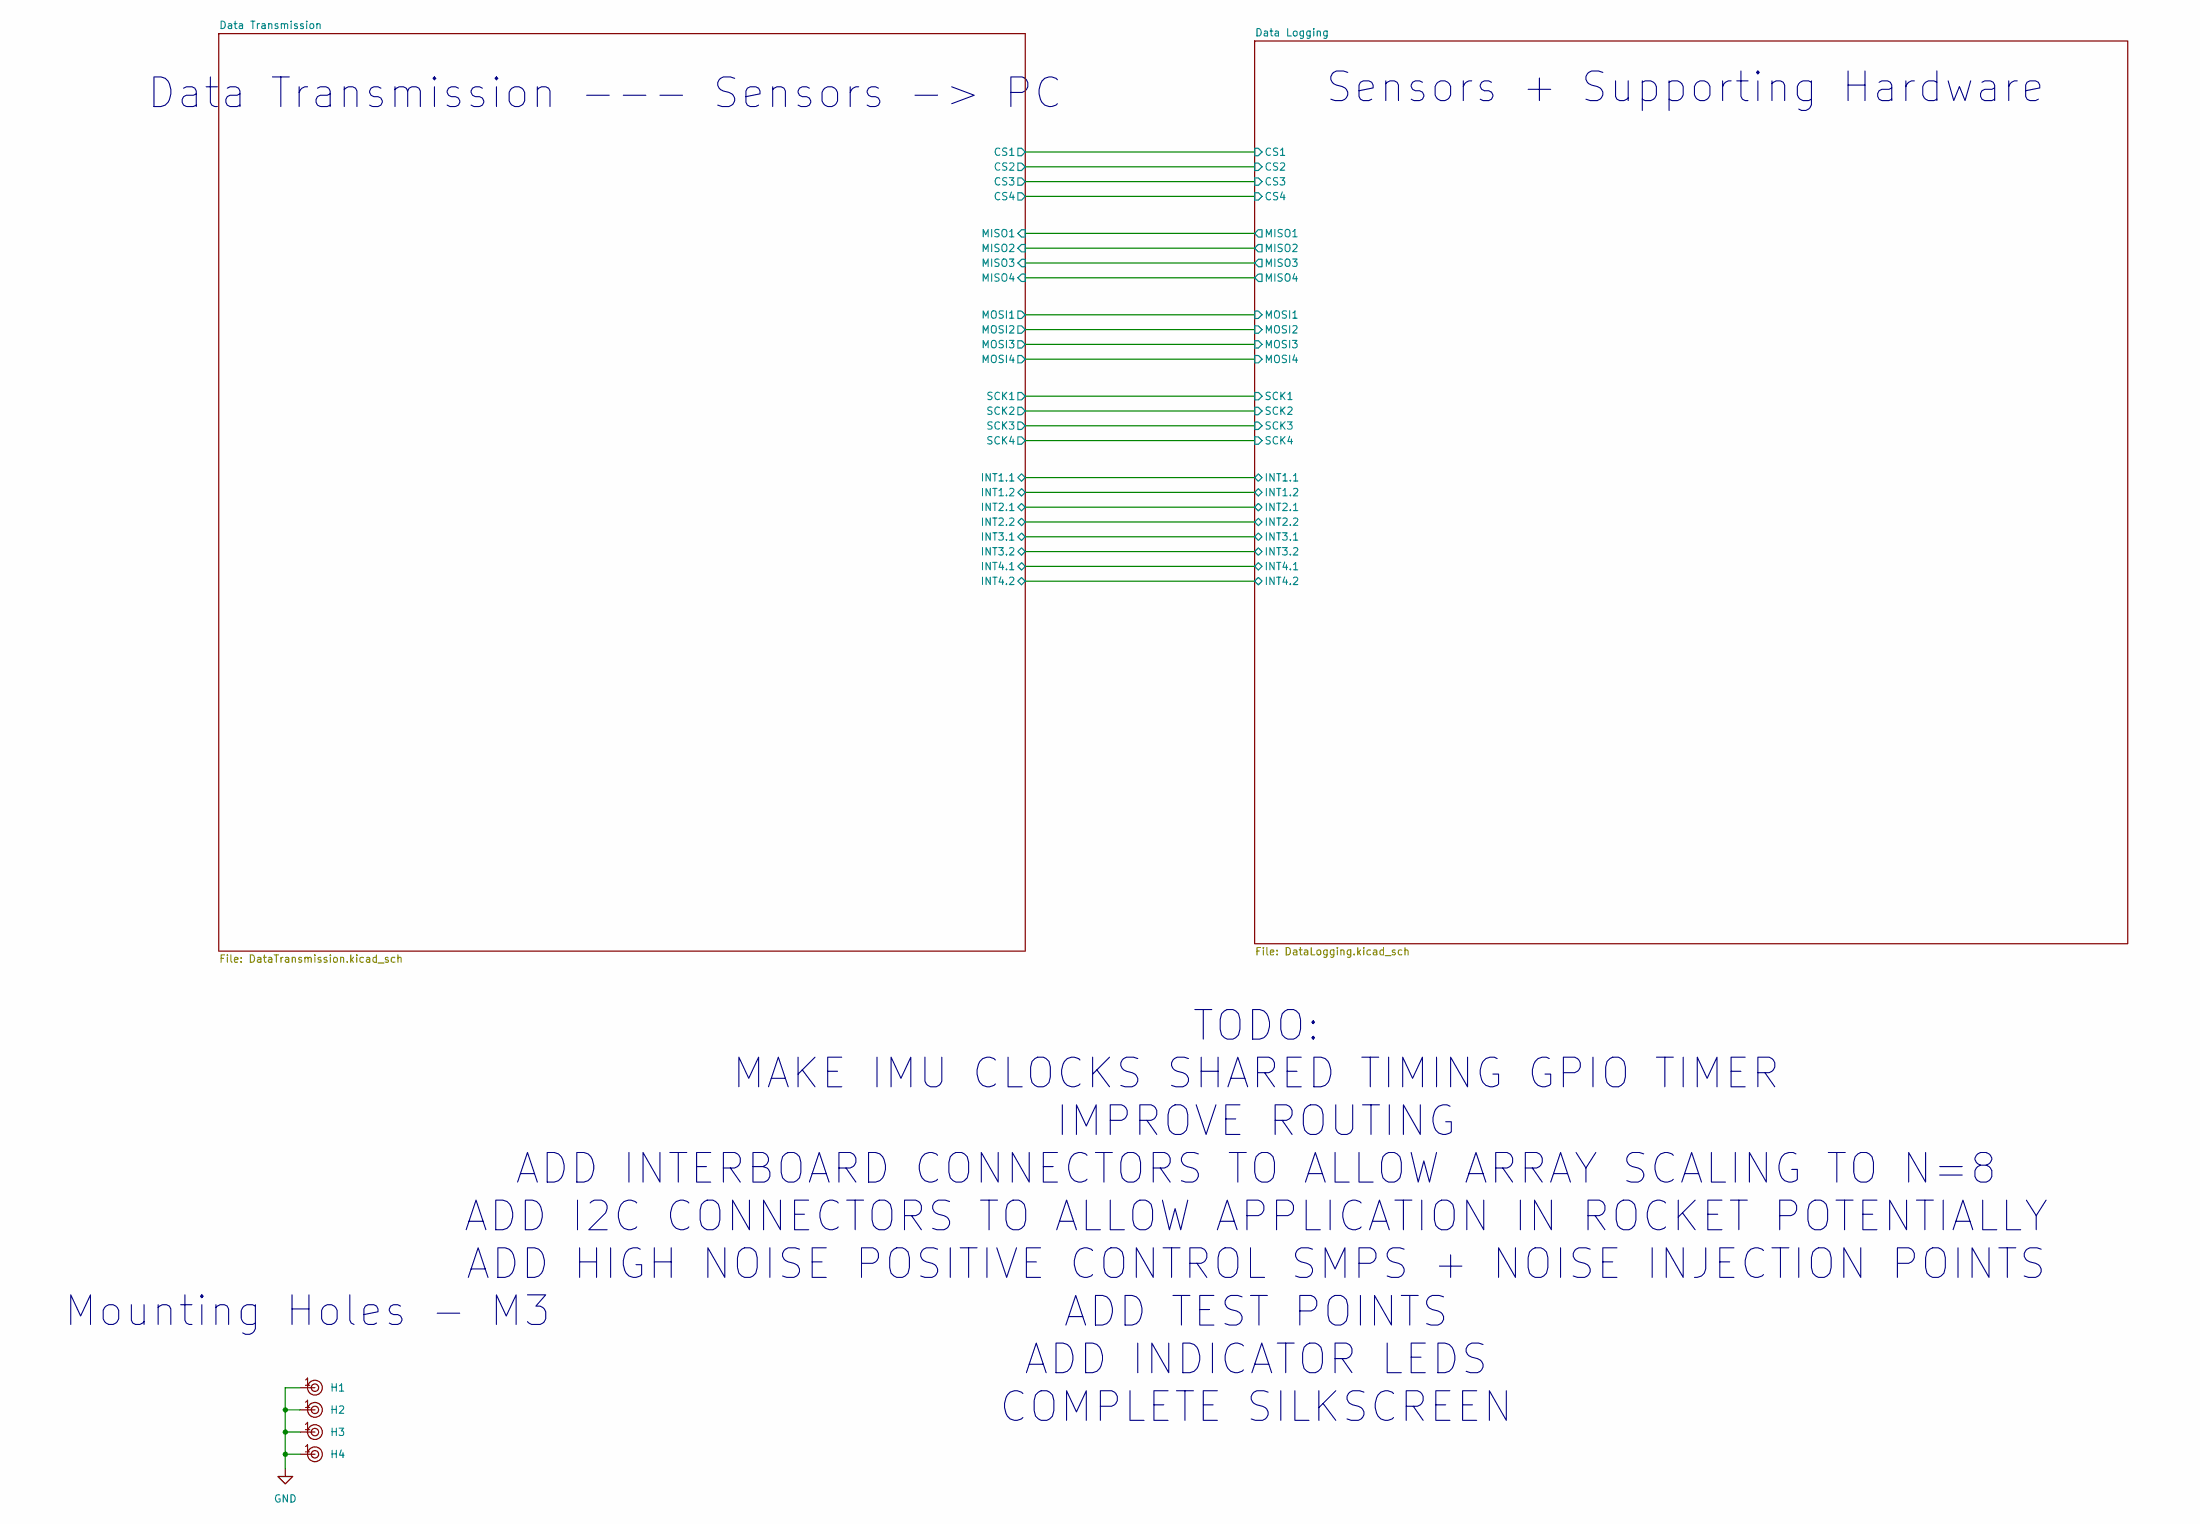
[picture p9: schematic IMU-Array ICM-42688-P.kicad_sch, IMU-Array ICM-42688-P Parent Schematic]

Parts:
H1, H2, H3, H4: Hole, 3mm

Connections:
GND: H1.1, H2.1, H3.1, H4.1; also elsewhere on the board

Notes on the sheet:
Sensors + Supporting Hardware
TODO: MAKE IMU CLOCKS SHARED TIMING GPIO TIMER IMPROVE ROUTING ADD INTERBOARD CONNECTORS TO ALLOW ARRAY SCALING TO N=8 ADD I2C CONNECTORS TO ALLOW APPLICATION IN ROCKET POTENTIALLY ADD HIGH NOISE POSITIVE CONTROL SMPS + NOISE INJECTION POINTS ADD TEST POINTS ADD INDICATOR LEDS COMPLETE SILKSCREEN
Data Transmission --- Sensors -> PC
Mounting Holes - M3

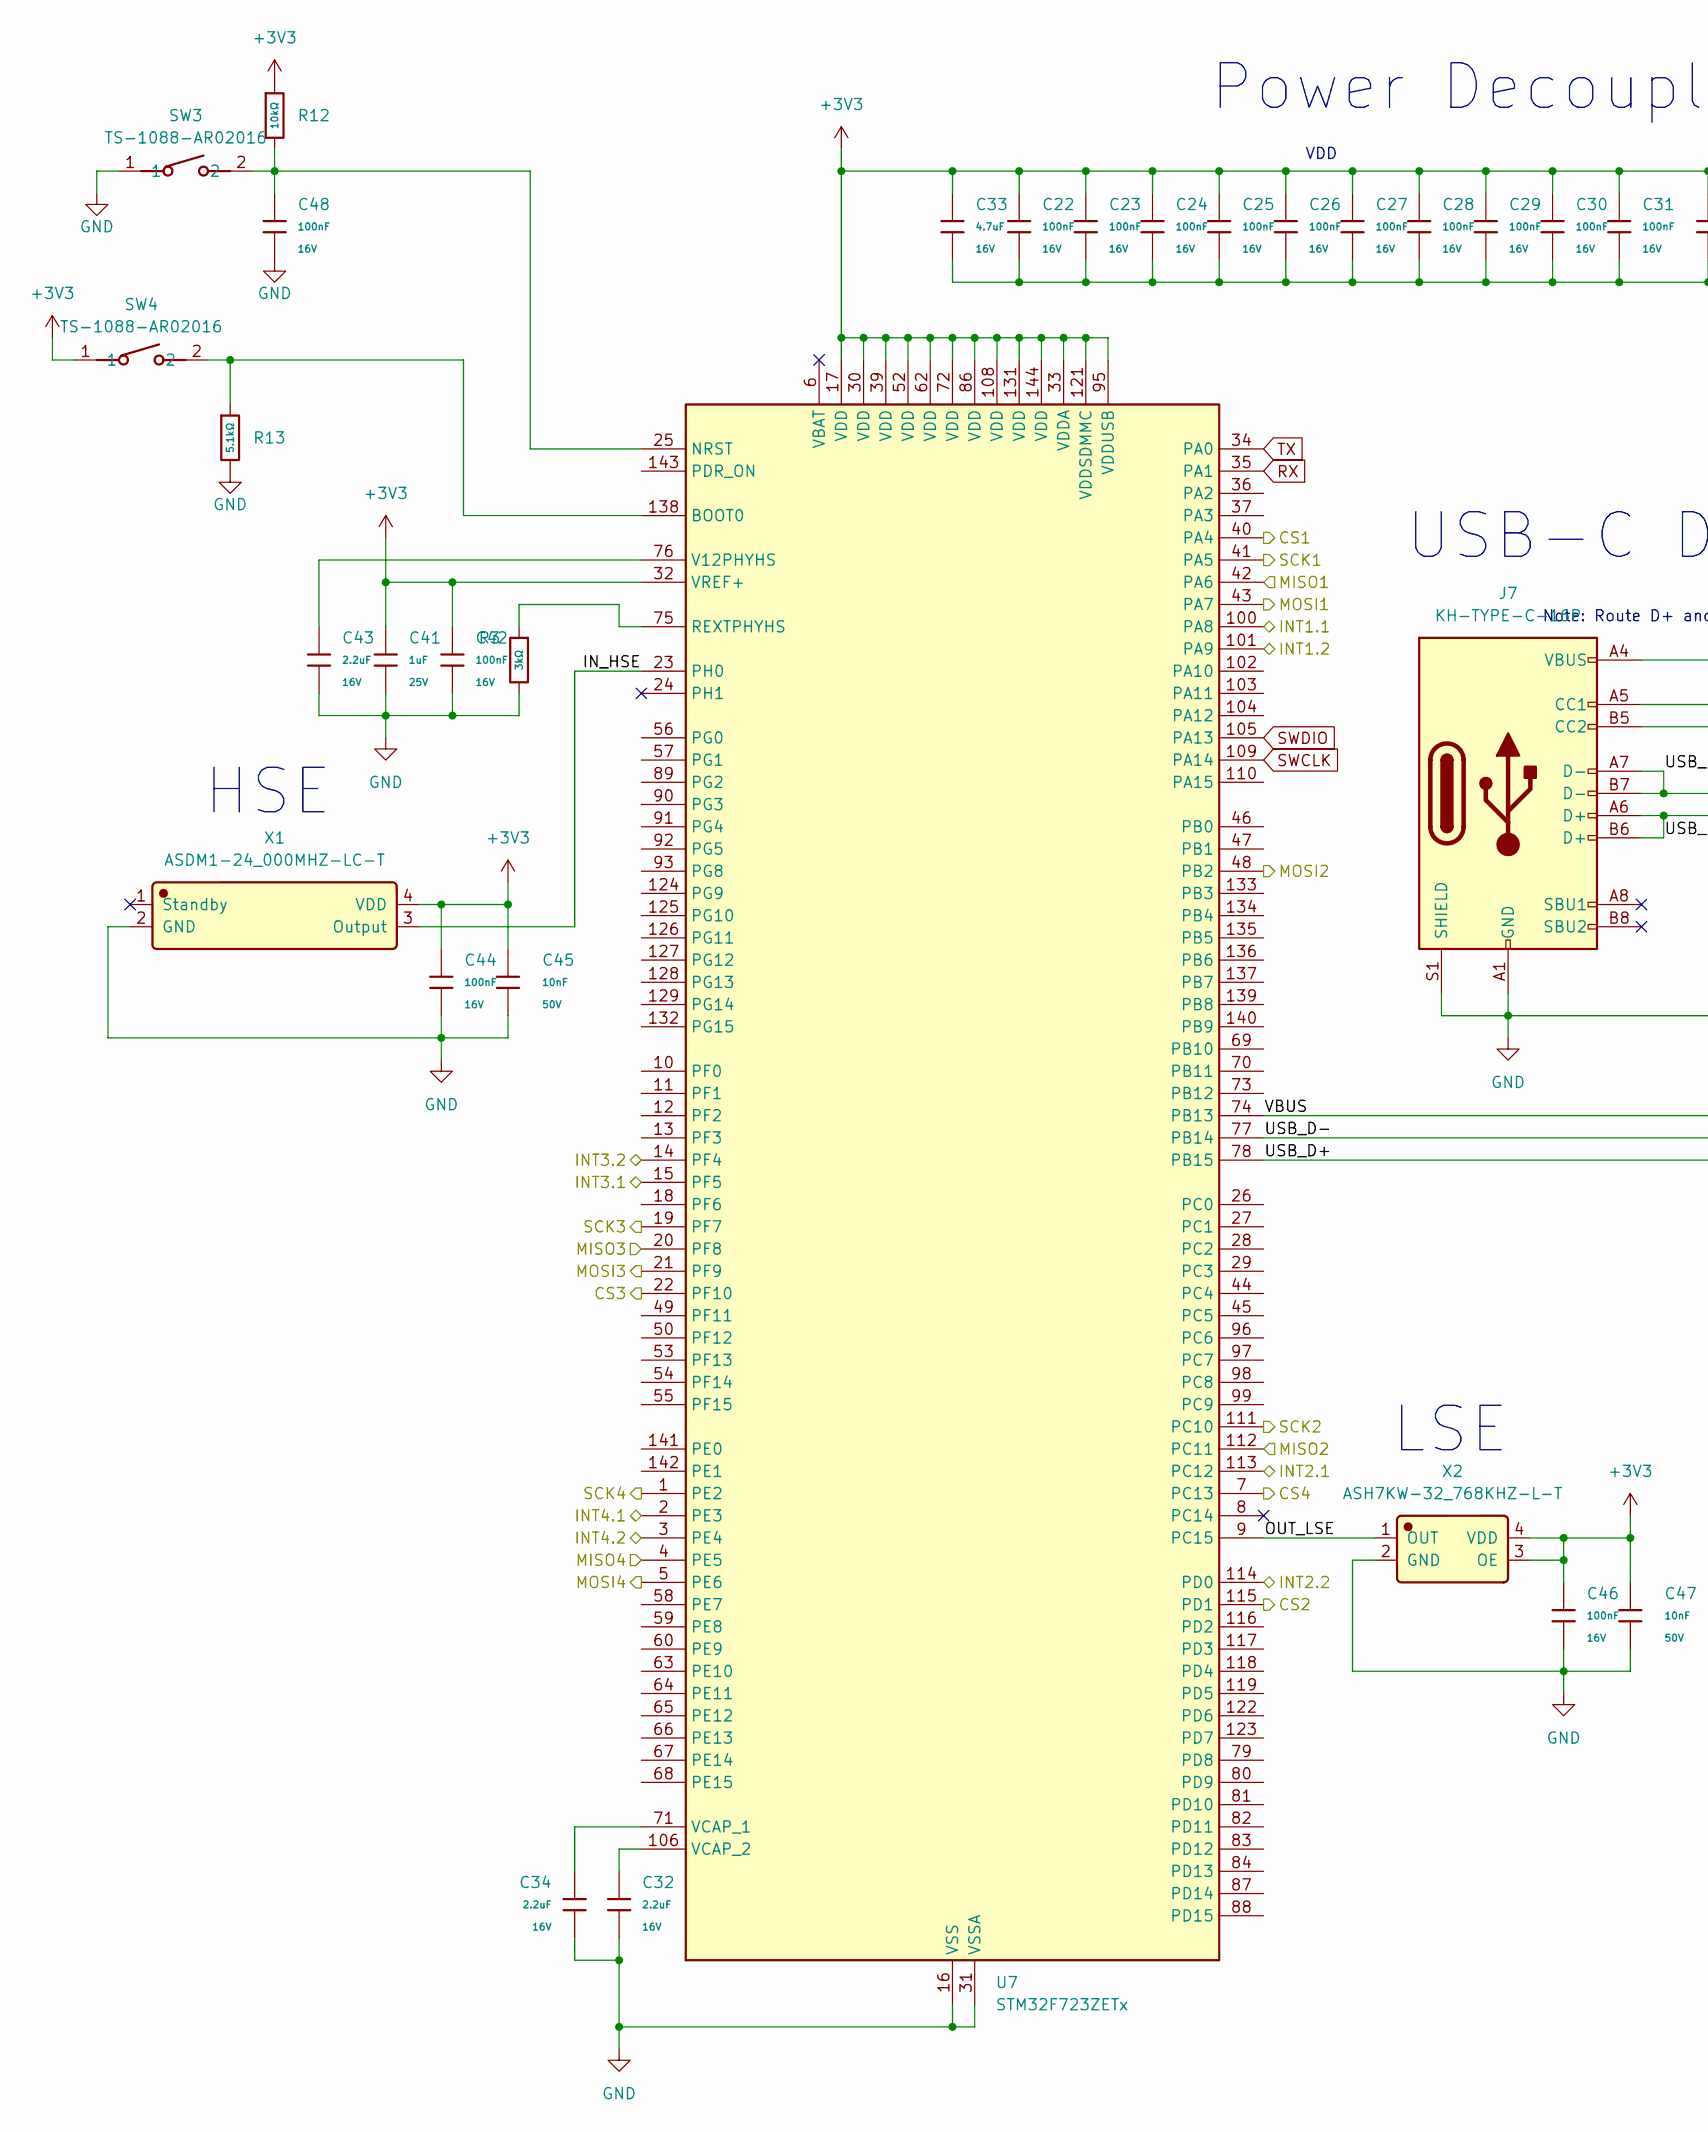
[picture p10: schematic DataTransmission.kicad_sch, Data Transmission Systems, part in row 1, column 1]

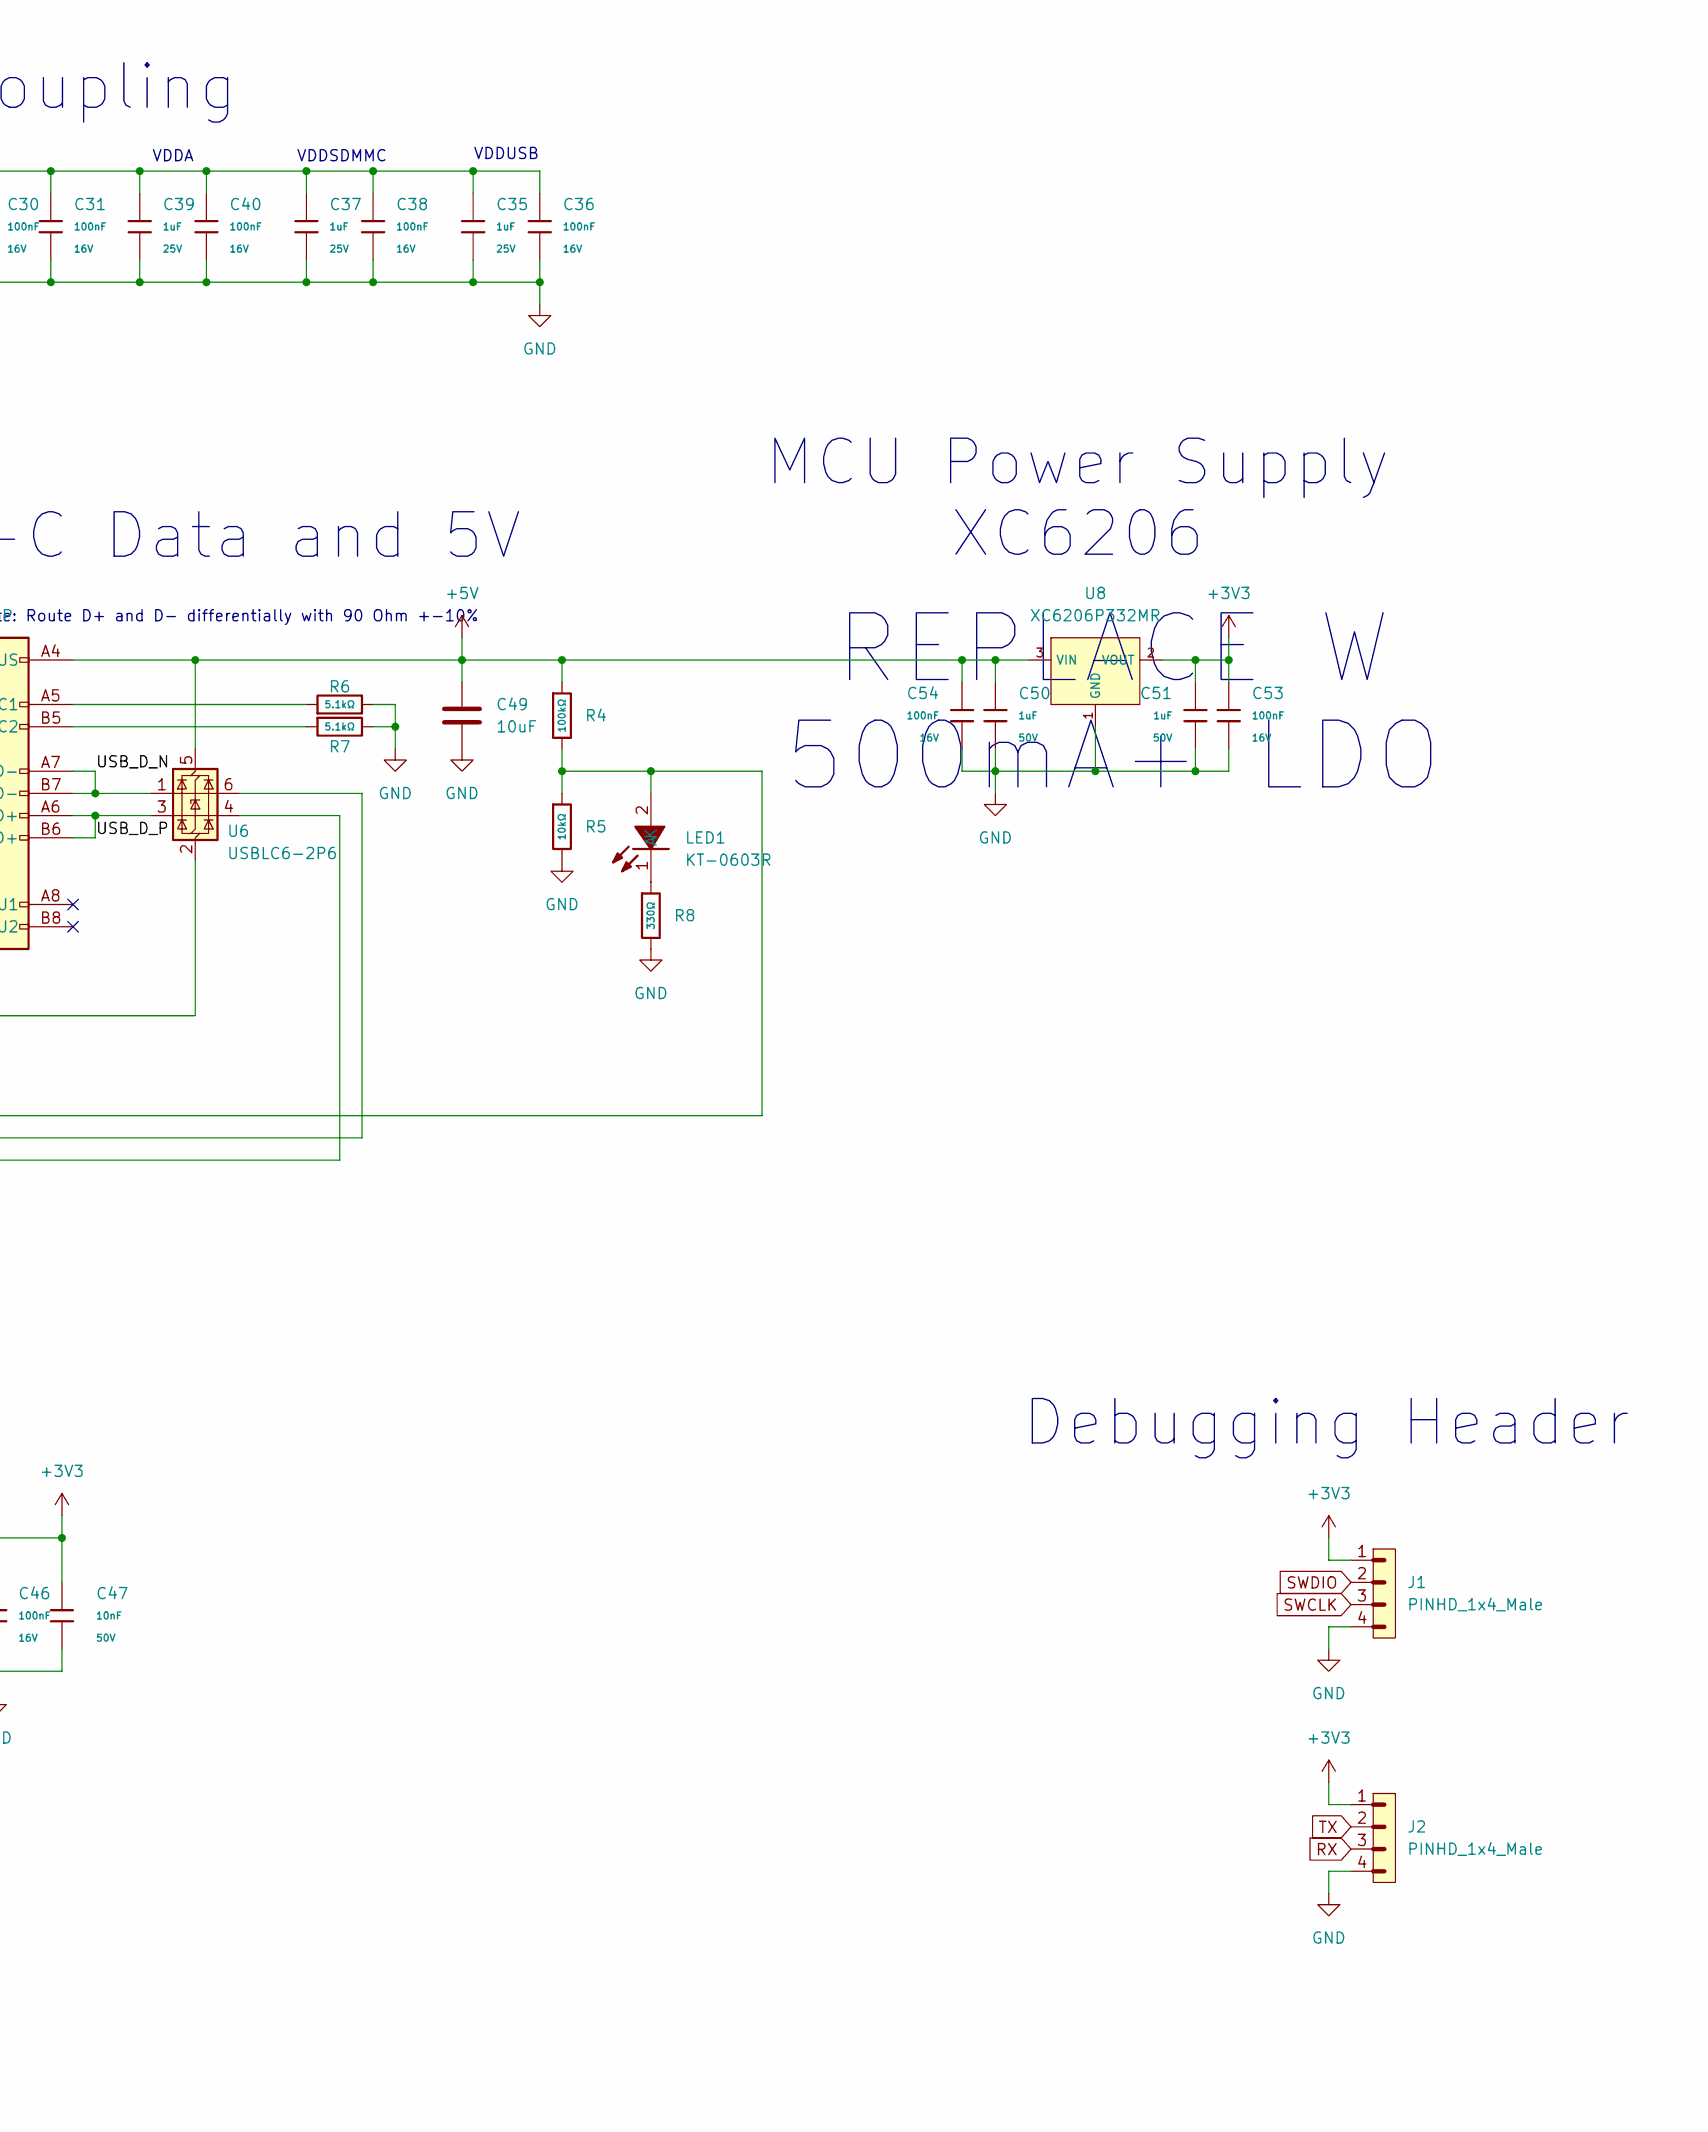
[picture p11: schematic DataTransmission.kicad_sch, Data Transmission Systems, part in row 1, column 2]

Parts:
C22, C23, C24, C25, C26, C27, C28, C29, C30, C31, C36, C38, C40, C42, C44, C46, C48, C53, C54: 100nF; C_0402; Voltage Rated 16V; Tolerance ±10%; Part CL05B104KO5NNNC; LCSC C1525
C32, C34, C43: 2.2uF; C_0603; Voltage Rated 16V; Tolerance ±10%; Part CL10A225KO8NNNC; LCSC C23630
C33: 4.7uF; C_0603; Voltage Rated 16V; Tolerance ±10%; Part CL10A475KO8NNNC; LCSC C19666
C35, C37, C39, C41: 1uF; C_0402; Voltage Rated 25V; Tolerance ±10%; Part CL05A105KA5NQNC; LCSC C52923
C45, C47: 10nF; C_0402; Voltage Rated 50V; Tolerance ±10%; Part CL05B103KB5NNNC; LCSC C15195
C49: 10uF; C_0603
C50, C51: 1uF; C_0603; Voltage Rated 50V; Tolerance ±10%; Part CL10A105KB8NNNC; LCSC C15849
J1, J2: PINHD_1x4_Male; PinHeader_1x04_P2.54mm_Vertical
J7: KH-TYPE-C-16P
LED1: KT-0603R; Manufacturer Part KT-0603R; LCSC C2286
R3: 3kΩ; R_0603; Overload Voltage (Max) 75V; Tolerance ±1%; Part 0603WAF3001T5E; LCSC C4211
R4: 100kΩ; R_0402; Overload Voltage (Max) 50V; Tolerance ±1%; Part 0402WGF1003TCE; LCSC C25741
R5, R12: 10kΩ; R_0402; Overload Voltage (Max) 50V; Tolerance ±1%; Part 0402WGF1002TCE; LCSC C25744
R6, R7, R13: 5.1kΩ; R_0402; Overload Voltage (Max) 50V; Tolerance ±1%; Part 0402WGF5101TCE; LCSC C25905
R8: 330Ω; R_0402; Overload Voltage (Max) 50V; Tolerance ±1%; Part 0402WGF3300TCE; LCSC C25104
SW3, SW4: TS-1088-AR02016; Manufacturer Part TS-1088-AR02016; LCSC C720477
U6: USBLC6-2P6; SOT-666
U7: STM32F723ZETx; LQFP-144_20x20mm_P0.5mm
U8: XC6206P332MR; SOT-23-3_L2.9-W1.6-P1.90-LS2.8-BR; Output Voltage 3.3V; Dropout Voltage 680mV@(100mA); Part XC6206P332MR-G; LCSC C5446
X1: ASDM1-24_000MHZ-LC-T; Manufacturer Part ASDM1-24.000MHZ-LC-T; LCSC C1987235
X2: ASH7KW-32_768KHZ-L-T; Manufacturer Part ASH7KW-32.768KHZ-L-T; LCSC C6277865

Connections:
+3V3: C22.1, C23.1, C24.1, C25.1, C26.1, C27.1, C28.1, C29.1, C30.1, C31.1, C33.1, C35.1, C36.1, C37.1, C38.1, C39.1, C40.1, C41.1, C42.1, C44.1, C45.1, C46.1, C47.1, C51.1, C53.1, J1.1, J2.1, R12.1, SW4.1, U7.17 (VDD), U7.30 (VDD), U7.32 (VREF+), U7.33 (VDDA), U7.39 (VDD), U7.52 (VDD), U7.62 (VDD), U7.72 (VDD), U7.86 (VDD), U7.95 (VDDUSB), U7.108 (VDD), U7.121 (VDDSDMMC), U7.131 (VDD), U7.144 (VDD), U8.2 (VOUT), X1.4 (VDD), X2.3 (OE), X2.4 (VDD)
+5V: C49.1, C50.1, C54.1, J7.A4 (VBUS), J7.A9 (VBUS), J7.B4 (VBUS), J7.B9 (VBUS), R4.1, U6.5 (VBUS), U8.3 (VIN); also elsewhere on the board
/Data Logging/CS1: U7.40 (PA4); also elsewhere on the board
/Data Logging/CS2: U7.115 (PD1); also elsewhere on the board
/Data Logging/CS3: U7.22 (PF10); also elsewhere on the board
/Data Logging/CS4: U7.7 (PC13); also elsewhere on the board
/Data Logging/INT1.1: U7.100 (PA8); also elsewhere on the board
/Data Logging/INT1.2: U7.101 (PA9); also elsewhere on the board
/Data Logging/INT2.1: U7.113 (PC12); also elsewhere on the board
/Data Logging/INT2.2: U7.114 (PD0); also elsewhere on the board
/Data Logging/INT3.1: U7.15 (PF5); also elsewhere on the board
/Data Logging/INT3.2: U7.14 (PF4); also elsewhere on the board
/Data Logging/INT4.1: U7.2 (PE3); also elsewhere on the board
/Data Logging/INT4.2: U7.3 (PE4); also elsewhere on the board
/Data Logging/MISO1: U7.42 (PA6); also elsewhere on the board
/Data Logging/MISO2: U7.112 (PC11); also elsewhere on the board
/Data Logging/MISO3: U7.20 (PF8); also elsewhere on the board
/Data Logging/MISO4: U7.4 (PE5); also elsewhere on the board
/Data Logging/MOSI1: U7.43 (PA7); also elsewhere on the board
/Data Logging/MOSI2: U7.48 (PB2); also elsewhere on the board
/Data Logging/MOSI3: U7.21 (PF9); also elsewhere on the board
/Data Logging/MOSI4: U7.5 (PE6); also elsewhere on the board
/Data Logging/SCK1: U7.41 (PA5); also elsewhere on the board
/Data Logging/SCK2: U7.111 (PC10); also elsewhere on the board
/Data Logging/SCK3: U7.19 (PF7); also elsewhere on the board
/Data Logging/SCK4: U7.1 (PE2); also elsewhere on the board
/Data Transmission/IN_HSE: U7.23 (PH0), X1.3 (Output)
/Data Transmission/OUT_LSE: U7.9 (PC15), X2.1 (OUT)
/Data Transmission/USB_D+: U6.4 (I/O2), U7.78 (PB15)
/Data Transmission/USB_D-: U6.6 (I/O1), U7.77 (PB14)
/Data Transmission/USB_D_N: J7.A7 (D-), J7.B7 (D-), U6.1 (I/O1)
/Data Transmission/USB_D_P: J7.A6 (D+), J7.B6 (D+), U6.3 (I/O2)
/Data Transmission/VBUS: LED1.2 (A), R4.2, R5.1, U7.74 (PB13)
GND: C22.2, C23.2, C24.2, C25.2, C26.2, C27.2, C28.2, C29.2, C30.2, C31.2, C32.2, C33.2, C34.2, C35.2, C36.2, C37.2, C38.2, C39.2, C40.2, C41.2, C42.2, C43.2, C44.2, C45.2, C46.2, C47.2, C48.2, C49.2, C50.2, C51.2, C53.2, C54.2, J1.4, J2.4, J7.A1 (GND), J7.A12 (GND), J7.B1 (GND), J7.B12 (GND), J7.S1 (SHIELD), R3.2, R5.2, R6.2, R7.2, R8.2, R13.2, SW3.1, U6.2 (GND), U7.16 (VSS), U7.31 (VSSA), U7.38 (VSS), U7.51 (VSS), U7.61 (VSS), U7.85 (VSS), U7.94 (VSS), U7.107 (VSS), U7.120 (VSS), U7.130 (VSS), U8.1 (GND), X1.2 (GND), X2.2 (GND); also elsewhere on the board
unnamed: J7.A5 (CC1), R6.1
unnamed: J7.B5 (CC2), R7.1
unnamed: LED1.1 (K), R8.1
unnamed: R13.1, SW4.2, U7.138 (BOOT0)
unnamed: C48.1, R12.2, SW3.2, U7.25 (NRST)
unnamed: R3.1, U7.75 (REXTPHYHS)
unnamed: C43.1, U7.76 (V12PHYHS)
unnamed: C34.1, U7.71 (VCAP_1)
unnamed: C32.1, U7.106 (VCAP_2)
RX: J2.3, U7.35 (PA1)
SWCLK: J1.3, U7.109 (PA14)
SWDIO: J1.2, U7.105 (PA13)
TX: J2.2, U7.34 (PA0)

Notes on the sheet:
VDDA
HSE
VDDUSB
VDDSDMMC
VDD
REPLACE W 500mA+ LDO
Debugging Header
MCU Power Supply XC6206
LSE
USB-C Data and 5V
Note: Route D+ and D- differentially with 90 Ohm +-10%
Power Decoupling

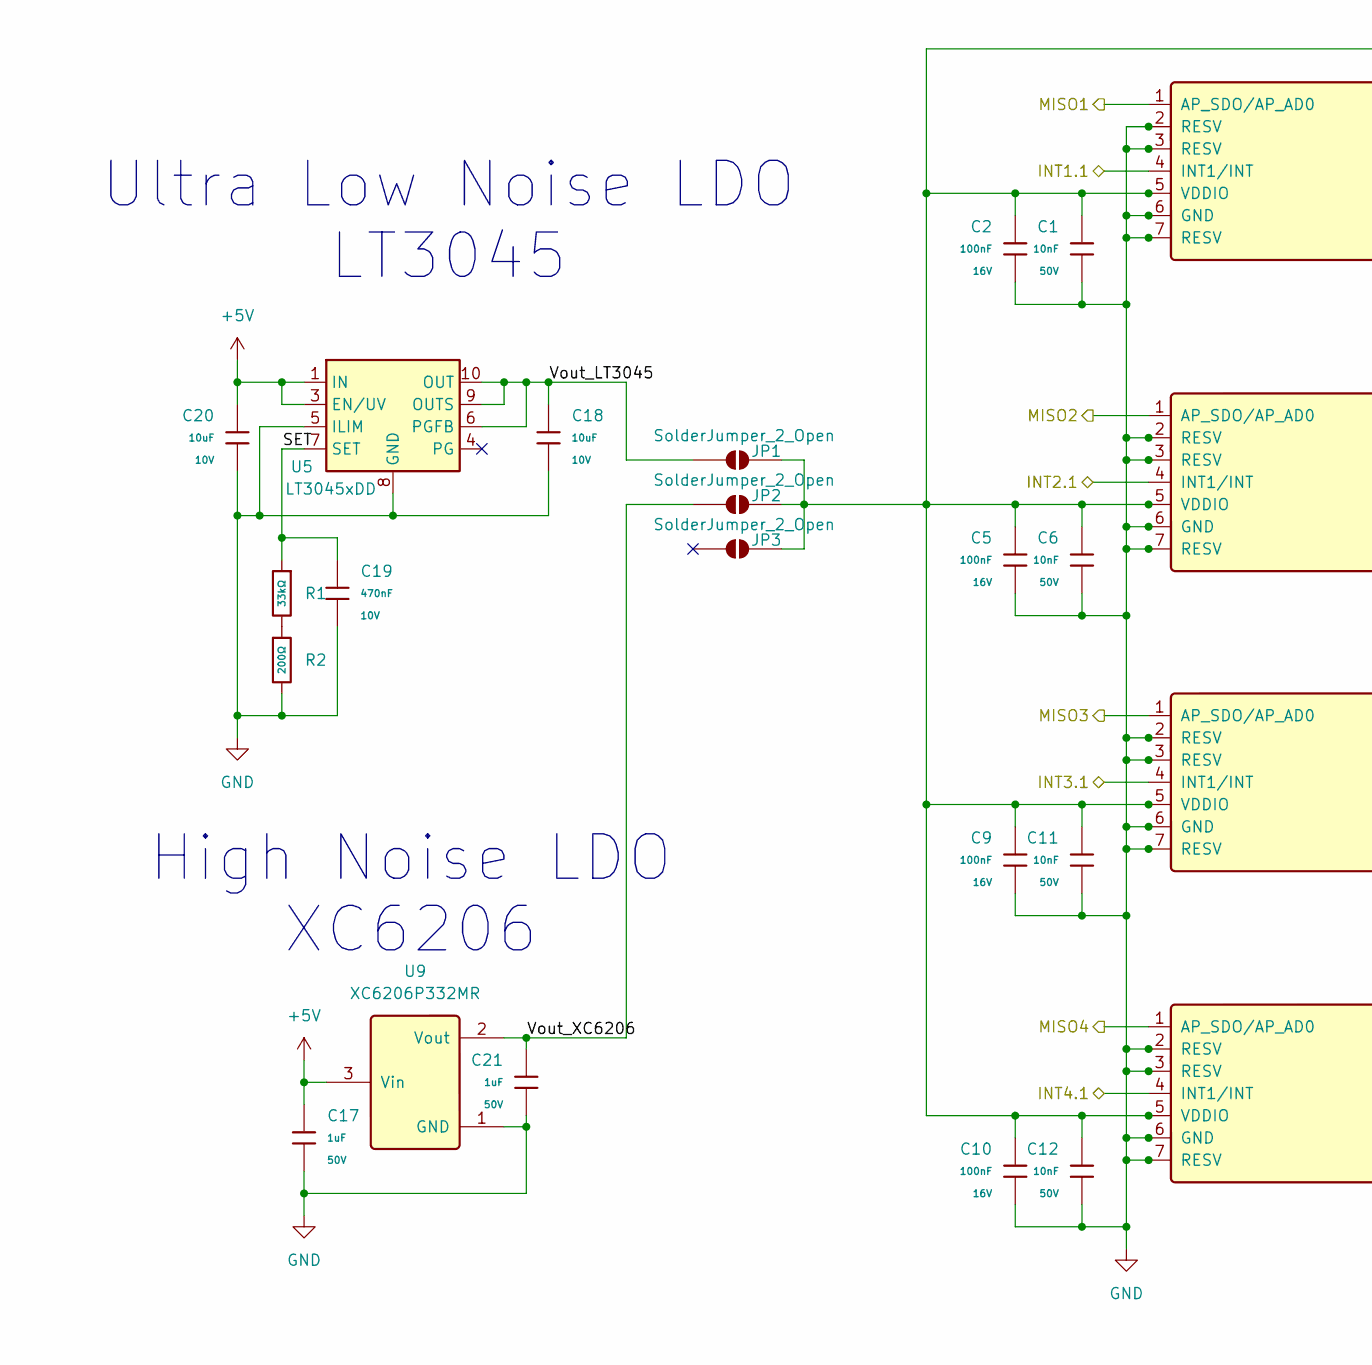
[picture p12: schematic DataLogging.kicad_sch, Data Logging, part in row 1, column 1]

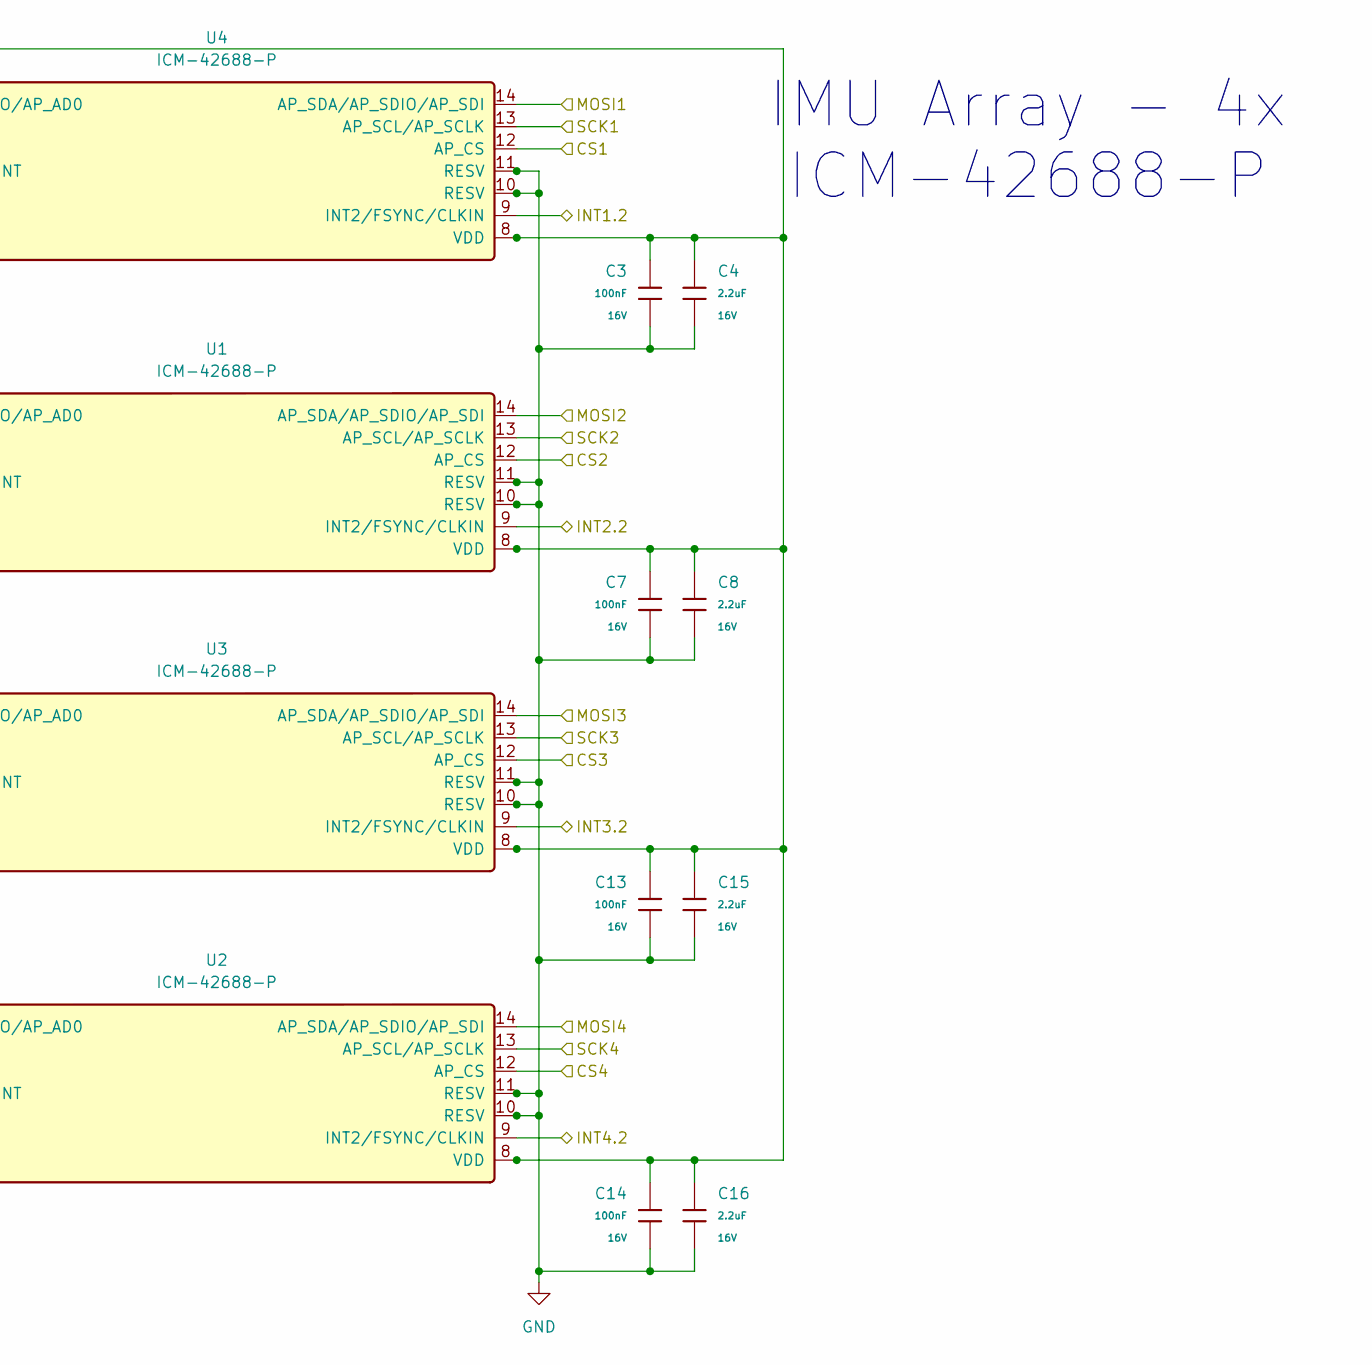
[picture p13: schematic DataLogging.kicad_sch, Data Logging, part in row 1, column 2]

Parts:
C1, C6, C11, C12: 10nF; C_0402; Voltage Rated 50V; Tolerance ±10%; Part CL05B103KB5NNNC; LCSC C15195
C2, C3, C5, C7, C9, C10, C13, C14: 100nF; C_0402; Voltage Rated 16V; Tolerance ±10%; Part CL05B104KO5NNNC; LCSC C1525
C4, C8, C15, C16: 2.2uF; C_0603; Voltage Rated 16V; Tolerance ±10%; Part CL10A225KO8NNNC; LCSC C23630
C17, C21: 1uF; C_0603; Voltage Rated 50V; Tolerance ±10%; Part CL10A105KB8NNNC; LCSC C15849
C18, C20: 10uF; C_0603; Voltage Rated 10V; Tolerance ±10%; Part CL10A106KP8NNNC; LCSC C19702
C19: 470nF; C_0402; Voltage Rated 10V; Tolerance ±10%; Part CL05A474KP5NNNC; LCSC C47339
JP1, JP2, JP3: SolderJumper_2_Open; SolderJumper-2_P1.3mm_Open_TrianglePad1.0x1.5mm
R1: 33kΩ; R_0402; Overload Voltage (Max) 50V; Tolerance ±1%; Part 0402WGF3302TCE; LCSC C25779
R2: 200Ω; R_0402; Overload Voltage (Max) 50V; Tolerance ±1%; Part 0402WGF2000TCE; LCSC C25087
U1, U2, U3, U4: ICM-42688-P; Manufacturer Part ICM-42688-P; LCSC C1850418
U5: LT3045xDD; DFN-10-1EP_3x3mm_P0.5mm_EP1.65x2.38mm
U9: XC6206P332MR; Manufacturer Part XC6206P332MR-G; LCSC C5446

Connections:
+5V: C17.1, C20.1, U5.1 (IN), U5.2 (IN), U5.3 (EN/UV), U9.3 (Vin); also elsewhere on the board
/Data Logging/CS1: U4.12 (AP_CS); also elsewhere on the board
/Data Logging/CS2: U1.12 (AP_CS); also elsewhere on the board
/Data Logging/CS3: U3.12 (AP_CS); also elsewhere on the board
/Data Logging/CS4: U2.12 (AP_CS); also elsewhere on the board
/Data Logging/INT1.1: U4.4 (INT1/INT); also elsewhere on the board
/Data Logging/INT1.2: U4.9 (INT2/FSYNC/CLKIN); also elsewhere on the board
/Data Logging/INT2.1: U1.4 (INT1/INT); also elsewhere on the board
/Data Logging/INT2.2: U1.9 (INT2/FSYNC/CLKIN); also elsewhere on the board
/Data Logging/INT3.1: U3.4 (INT1/INT); also elsewhere on the board
/Data Logging/INT3.2: U3.9 (INT2/FSYNC/CLKIN); also elsewhere on the board
/Data Logging/INT4.1: U2.4 (INT1/INT); also elsewhere on the board
/Data Logging/INT4.2: U2.9 (INT2/FSYNC/CLKIN); also elsewhere on the board
/Data Logging/MISO1: U4.1 (AP_SDO/AP_AD0); also elsewhere on the board
/Data Logging/MISO2: U1.1 (AP_SDO/AP_AD0); also elsewhere on the board
/Data Logging/MISO3: U3.1 (AP_SDO/AP_AD0); also elsewhere on the board
/Data Logging/MISO4: U2.1 (AP_SDO/AP_AD0); also elsewhere on the board
/Data Logging/MOSI1: U4.14 (AP_SDA/AP_SDIO/AP_SDI); also elsewhere on the board
/Data Logging/MOSI2: U1.14 (AP_SDA/AP_SDIO/AP_SDI); also elsewhere on the board
/Data Logging/MOSI3: U3.14 (AP_SDA/AP_SDIO/AP_SDI); also elsewhere on the board
/Data Logging/MOSI4: U2.14 (AP_SDA/AP_SDIO/AP_SDI); also elsewhere on the board
/Data Logging/SCK1: U4.13 (AP_SCL/AP_SCLK); also elsewhere on the board
/Data Logging/SCK2: U1.13 (AP_SCL/AP_SCLK); also elsewhere on the board
/Data Logging/SCK3: U3.13 (AP_SCL/AP_SCLK); also elsewhere on the board
/Data Logging/SCK4: U2.13 (AP_SCL/AP_SCLK); also elsewhere on the board
/Data Logging/SET: C19.1, R1.1, U5.7 (SET)
/Data Logging/Vout_LT3045: C18.1, JP1.1 (A), U5.6 (PGFB), U5.9 (OUTS), U5.10 (OUT)
/Data Logging/Vout_XC6206: C21.1, JP2.1 (A), U9.2 (Vout)
GND: C1.2, C2.2, C3.2, C4.2, C5.2, C6.2, C7.2, C8.2, C9.2, C10.2, C11.2, C12.2, C13.2, C14.2, C15.2, C16.2, C17.2, C18.2, C19.2, C20.2, C21.2, R2.2, U1.2 (RESV), U1.3 (RESV), U1.6 (GND), U1.7 (RESV), U1.10 (RESV), U1.11 (RESV), U2.2 (RESV), U2.3 (RESV), U2.6 (GND), U2.7 (RESV), U2.10 (RESV), U2.11 (RESV), U3.2 (RESV), U3.3 (RESV), U3.6 (GND), U3.7 (RESV), U3.10 (RESV), U3.11 (RESV), U4.2 (RESV), U4.3 (RESV), U4.6 (GND), U4.7 (RESV), U4.10 (RESV), U4.11 (RESV), U5.5 (ILIM), U5.8 (GND), U5.11 (GND), U9.1 (GND); also elsewhere on the board
unnamed: C1.1, C2.1, C3.1, C4.1, C5.1, C6.1, C7.1, C8.1, C9.1, C10.1, C11.1, C12.1, C13.1, C14.1, C15.1, C16.1, JP1.2 (B), JP2.2 (B), JP3.2 (B_2), U1.5 (VDDIO), U1.8 (VDD), U2.5 (VDDIO), U2.8 (VDD), U3.5 (VDDIO), U3.8 (VDD), U4.5 (VDDIO), U4.8 (VDD)
unnamed: R1.2, R2.1

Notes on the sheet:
IMU Array - 4x ICM-42688-P
High Noise LDO XC6206
Ultra Low Noise LDO LT3045

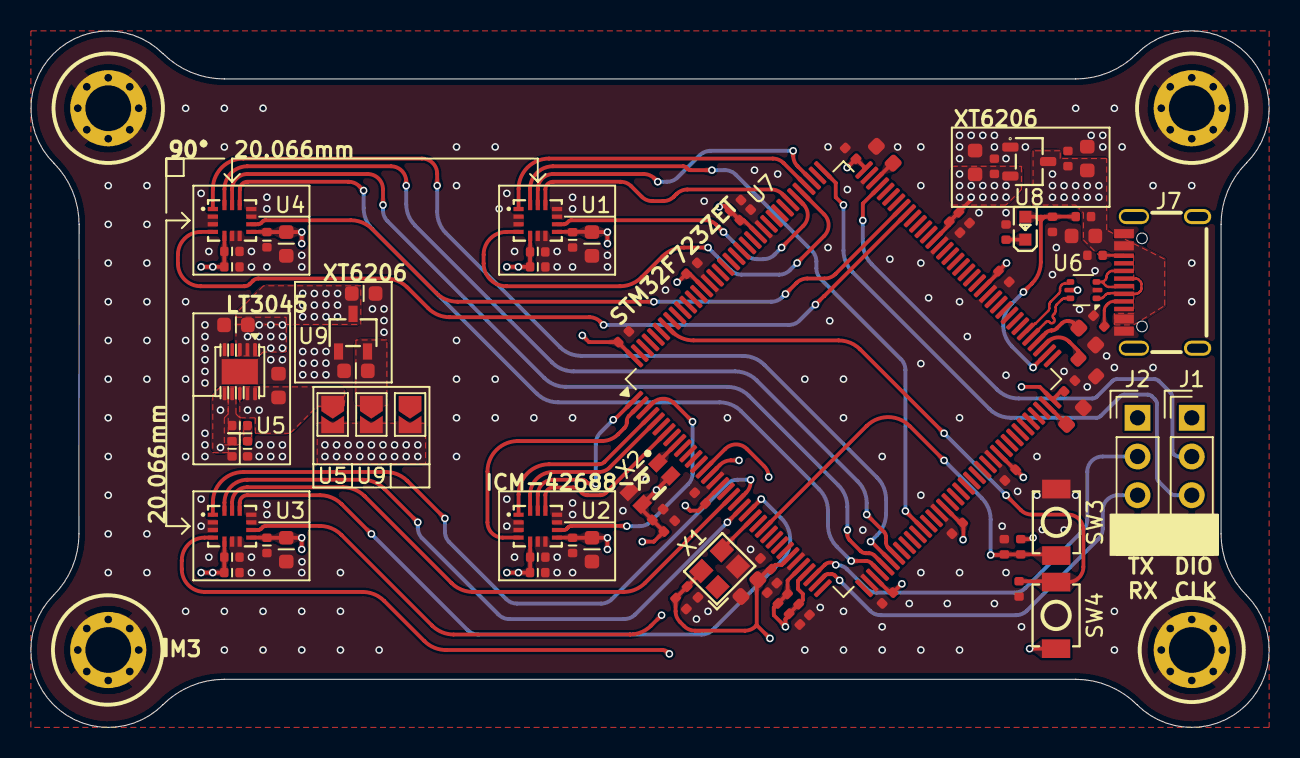
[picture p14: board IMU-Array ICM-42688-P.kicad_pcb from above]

Board: 4 copper layers, 81.3 x 45.7 mm, 87 parts (0 on the bottom side), 52 nets.

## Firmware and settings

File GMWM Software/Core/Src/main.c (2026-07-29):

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
/* Includes ------------------------------------------------------------------*/
#include "main.h"
#include "fatfs.h"
#include "usb_device.h"

/* USER CODE BEGIN Includes */
#include "usbd_cdc_if.h"
#include "usbd_composite.h"
#include "sheppard_config.h"
#include "console.h"
#include "boot_ctrl.h"
#include "fwupdate.h"
#include "timebase.h"
#include "bus.h"

/* imu_icm42688.h is deliberately NOT included here.
 *
 * main.c still carries the bring-up ICM code -- its own ICM_* register
 * defines and a static icm_write8() -- which collides with the driver's
 * header on about twenty macros and one function name. That collision is a
 * symptom, not a problem to paper over: main.c should not own ICM register
 * knowledge at all, and the module split (TN-18, refactor task) deletes the
 * legacy block entirely.
 *
 * Until then main.c needs exactly one symbol from the driver, so it declares
 * that one rather than dragging in a header it conflicts with. Remove this
 * line and add the include once the legacy block is gone.
 */
void icm_console_init(void);
void validate_console_init(void);
void storage_console_init(void);
void xfer_console_init(void);
#include "led.h"
#include "seq.h"
void sampler_on_int(uint16_t gpio_pin);   /* sampler.h; declared to avoid
                                             pulling in bus.h/record.h here */
#include <stdarg.h>
#include <stdio.h>
#include <stdlib.h>
#include <string.h>
/* USER CODE END Includes */

/* USER CODE BEGIN PTD */
typedef struct {
  SPI_HandleTypeDef *hspi;
  GPIO_TypeDef      *cs_port;   uint16_t cs_pin;
  GPIO_TypeDef      *led_port;  uint16_t led_pin;
  uint16_t           int_pin;                 /* data-ready EXTI pin */
} bus_t;
/* USER CODE END PTD */

/* USER CODE BEGIN PD */
#define LED_ON   GPIO_PIN_SET      /* swap these two if LEDs are active-low */
#define LED_OFF  GPIO_PIN_RESET
#define SPI_TMO  100U              /* ms/transfer; timeout guards a dead bus */
#define DUMP_REGS        16U       /* how many regs to hex-dump on a dead bus   */
#define RATE_WINDOW_MS   10000U    /* default `rate` measurement window         */



#define ICM_TEMP_DATA1   0x1D
#define ICM_ACCEL_DATA_X1 0x1F   /* 6 bytes: X1 X0 Y1 Y0 Z1 Z0 */
#define ICM_GYRO_DATA_X1  0x25   /* 6 bytes: X1 X0 Y1 Y0 Z1 Z0 */
#define ICM_PWR_MGMT0     0x4E


#define ICM_GYRO_CONFIG0   0x4F
#define ICM_ACCEL_CONFIG0  0x50

/* ---- ICM-42688-P ----  FS_SEL=000 (±2000 dps / ±16 g) | ODR 0x8 = 100 Hz */
#define ICM_FS_MAX_ODR_100HZ  ((0x0U << 5) | 0x08U)   /* was 0x0A = 25 Hz */

#define ERR_HERE()  do { g_err_file = __FILE__; g_err_line = __LINE__; Error_Handler(); } while (0)

/* ---- ISM330DHCX ---- */
#define ISM_CTRL1_XL      0x10
#define ISM_CTRL2_G       0x11
#define ISM_CTRL3_C       0x12
#define ISM_OUT_TEMP_L    0x20   /* burst 14 B: temp(2) gyro(6) accel(6) */
/* ODR 104 Hz (0010<<4) | FS_XL 01 (±16 g) <<2 */
#define ISM_CTRL1_XL_VAL  0x44
/* ODR 104 Hz (0010<<4) | FS_G 11 (±2000 dps) <<2 | FS_125=0 | FS_4000=0 */
#define ISM_CTRL2_G_VAL   0x4C
/* BDU=1 (bit6) prevents torn LSB/MSB across samples; IF_INC=1 (bit2) for bursts */
#define ISM_CTRL3_C_VAL   0x44

/* ---- BMI323 ---- */
#define BMI_ACC_CONF      0x20
#define BMI_GYR_CONF      0x21
#define BMI_ACC_X         0x03   /* burst 7 words: accel(3) gyro(3) temp(1) */
/* mode 7 (high-perf) <<12 | range <<4 | ODR 100 Hz (0x6) */
#define BMI_ACC_CONF_VAL  0x7038 /* ±16 g  */
#define BMI_GYR_CONF_VAL  0x7048 /* ±2000 dps */

#define ICM_REG_BANK_SEL          0x76
#define ICM_GYRO_CONFIG1          0x51   /* [3:2] GYRO_UI_FILT_ORD          */
#define ICM_GYRO_ACCEL_CONFIG0    0x52   /* [7:4] ACCEL bw, [3:0] GYRO bw   */
#define ICM_ACCEL_CONFIG1         0x53   /* [4:3] ACCEL_UI_FILT_ORD         */
/* bank 1 */
#define ICM_GYRO_CFG_STATIC3      0x0C
#define ICM_GYRO_CFG_STATIC4      0x0D
#define ICM_GYRO_CFG_STATIC5      0x0E
/* bank 2 */
#define ICM_ACCEL_CFG_STATIC2     0x03   /* [6:1] ACCEL_AAF_DELT, [0] AAF_DIS */
#define ICM_ACCEL_CFG_STATIC3     0x04
#define ICM_ACCEL_CFG_STATIC4     0x05

/* UI filter bandwidth code: 0 = ODR/2 (matches BMI323 bw bit = 0 and the
   ISM330DHCX default chain). Both nibbles of 0x52 set to 0.               */
#define ICM_UI_BW_ODR_OVER_2      0x00

/* AAF ~42 Hz, the lowest cutoff the part supports.
   [VERIFY] these three numbers against the AAF table in DS-000347 §5.3
   before any data you intend to keep — I have not confirmed them from the
   datasheet table in this session, only the register addresses above.     */
#define ICM_AAF_DELT              1
#define ICM_AAF_DELTSQR           1
#define ICM_AAF_BITSHIFT          15


#define RTC_MAGIC  0x5348u   /* 'SH' — marks the RTC as already set */

/* ---- data-ready interrupt registers ----
   [verify] bit-field values below are from driver convention, not the
   datasheets. Step 2.9 validates them empirically. */
#define ICM_INT_CONFIG    0x14
#define ICM_INT_CONFIG1   0x64
#define ICM_INT_SOURCE0   0x65
#define ICM_INT_STATUS    0x2D

#define ISM_INT1_CTRL     0x0D
#define ISM_STATUS_REG    0x1E

#define BMI_IO_INT_CTRL   0x38
#define BMI_INT_MAP2      0x3B
#define BMI_INT_STATUS1   0x0D

/* [verify] COUNTER_BDR_REG1 addr/bit against the ISM330DHCX datasheet */
#define ISM_COUNTER_BDR_REG1  0x0B
#define ISM_DRDY_PULSED       0x80   /* bit 7 */

/* USER CODE END PD */

ADC_HandleTypeDef hadc1;

I2C_HandleTypeDef hi2c1;

RTC_HandleTypeDef hrtc;

SD_HandleTypeDef hsd2;

SPI_HandleTypeDef hspi1;
SPI_HandleTypeDef hspi3;
SPI_HandleTypeDef hspi4;
SPI_HandleTypeDef hspi5;
DMA_HandleTypeDef hdma_spi1_rx;
DMA_HandleTypeDef hdma_spi1_tx;
DMA_HandleTypeDef hdma_spi3_rx;
DMA_HandleTypeDef hdma_spi3_tx;

TIM_HandleTypeDef htim2;

UART_HandleTypeDef huart4;
UART_HandleTypeDef huart1;

/* USER CODE BEGIN PV */
static const bus_t g_buses[4] = {
  { &hspi1, CS_1_GPIO_Port, CS_1_Pin, LED_1_GPIO_Port, LED_1_Pin, INT1_1_Pin },  /* slot 1 ICM */
  { &hspi3, CS_2_GPIO_Port, CS_2_Pin, LED_2_GPIO_Port, LED_2_Pin, INT2_1_Pin },  /* slot 2 ICM */
  { &hspi5, CS_3_GPIO_Port, CS_3_Pin, LED_3_GPIO_Port, LED_3_Pin, INT3_1_Pin },  /* slot 3 ISM */
  { &hspi4, CS_4_GPIO_Port, CS_4_Pin, LED_4_GPIO_Port, LED_4_Pin, INT4_1_Pin },  /* slot 4 BMI */
};

static volatile uint32_t g_drdy_count[4] = {0};
static volatile uint32_t g_drdy_flag     = 0;   /* bit i set = bus i has new data */

static const char *g_err_file = "unknown";
static int         g_err_line = 0;

extern USBD_HandleTypeDef hUsbDeviceHS;   /* defined in usb_device.c */

/* Console commands owned by main.c. Handlers are defined in USER CODE 4.
   The prototypes must be HERE and not in USER CODE PFP: PV is emitted before
   PFP, so the table below would otherwise reference undeclared identifiers.
   Modules added later register their own tables rather than extending this. */
static void cmd_scan(int argc, char **argv);
static void cmd_sd(int argc, char **argv);
static void cmd_burst(int argc, char **argv);
static void cmd_time(int argc, char **argv);
static void cmd_rate(int argc, char **argv);
static void cmd_tick(int argc, char **argv);

/* Non-blocking data-ready rate measurement. Started by `rate`, completed by
   rate_task() in the main loop. */
static uint32_t g_rate_c0[4]  = {0};
static uint32_t g_rate_t0     = 0;
static uint32_t g_rate_window = 0;
static uint8_t  g_rate_active = 0;

static const console_cmd_t g_main_cmds[] = {
  { "scan",  "identify all four buses and dump one sample", cmd_scan  },
  { "tick",  "tick [s] - check the 1 us timebase against SysTick", cmd_tick },
  { "rate",  "rate [s|stop] - measure true ODR, runs in the background", cmd_rate },
  { "sd",    "mount the card and run the FS self-test", cmd_sd    },
  { "burst", "burst <n> - CDC throughput test, n x 512 B", cmd_burst },
  { "time",  "time YYYY-MM-DD HH:MM:SS - set the RTC", cmd_time  },
};
/* USER CODE END PV */

void SystemClock_Config(void);
static void MPU_Config(void);
static void MX_GPIO_Init(void);
static void MX_DMA_Init(void);
static void MX_SPI1_Init(void);
static void MX_SPI3_Init(void);
static void MX_SPI4_Init(void);
static void MX_SPI5_Init(void);
static void MX_UART4_Init(void);
static void MX_ADC1_Init(void);
static void MX_I2C1_Init(void);
static void MX_SDMMC2_SD_Init(void);
static void MX_USART1_UART_Init(void);
static void MX_RTC_Init(void);
static void MX_TIM2_Init(void);
/* USER CODE BEGIN PFP */



static uint8_t spi_read8(const bus_t *b, uint8_t reg);
static uint8_t bmi323_chipid(const bus_t *b);
static int     bus_present(const bus_t *b);
static void uart_log(const char *fmt, ...);
static void print_banner(void);
static void scan_all_buses(void);
static void hexdump_bus(const bus_t *b, uint8_t start_reg, uint8_t count);




static void icm_write8(const bus_t *b, uint8_t reg, uint8_t val);
static void icm_burst_read(const bus_t *b, uint8_t reg, uint8_t *dst, uint8_t n);
static void icm_mvp_log(const bus_t *b, int idx);


static void error_dump(void);





static void fs_test(void);


static void ism_configure(const bus_t *b);
static void ism_mvp_log(const bus_t *b, int idx);
static void bmi_write16(const bus_t *b, uint8_t reg, uint16_t val);
static uint16_t bmi_read16(const bus_t *b, uint8_t reg);
static void bmi_burst16(const bus_t *b, uint8_t reg, uint16_t *dst, uint8_t nwords);
static void bmi_configure(const bus_t *b);
static void bmi_mvp_log(const bus_t *b, int idx);
static void sensor_configure(const bus_t *b);
static void sensor_mvp_log(const bus_t *b, int idx);

static void icm_bank(const bus_t *b, uint8_t bank);
static void icm_rmw(const bus_t *b, uint8_t reg, uint8_t mask, uint8_t val);
static void icm_configure_matched(const bus_t *b);


static int  cdc_write(const uint8_t *buf, uint16_t len);
static void cdc_burst(uint32_t nchunks);

static void rtc_init_once(void);
static void rtc_print(void);


static void icm_enable_drdy(const bus_t *b);
static void ism_enable_drdy(const bus_t *b);
static void bmi_enable_drdy(const bus_t *b);

/* Console command handlers are prototyped in USER CODE PV, immediately above
   the table that references them -- see the note there. */
static void rate_task(void);

/* USER CODE END PFP */

/**
  * @brief  The application entry point.
  * @retval int
  */
int main(void)
{

  /* USER CODE BEGIN 1 */
#if SHEPPARD_VTOR_RELOCATE
  /* Point the vector table at wherever this image was linked. A no-op while
     SHEPPARD_APP_BASE is 0x08000000; load-bearing the moment the DFU loader
     occupies the low sectors and the application moves to 0x08010000.
     Must happen before HAL_Init() enables SysTick, or the first tick vectors
     into the loader's table. */
  SCB->VTOR = SHEPPARD_APP_BASE;
  __DSB();
#endif
  /* USER CODE END 1 */

  /* MPU Configuration--------------------------------------------------------*/
  MPU_Config();

  /* MCU Configuration--------------------------------------------------------*/

  /* Reset of all peripherals, Initializes the Flash interface and the Systick. */
  HAL_Init();

  /* Configure the system clock */
  SystemClock_Config();

  /* Initialize all configured peripherals */
  MX_GPIO_Init();
  MX_DMA_Init();
  MX_SPI1_Init();
  MX_SPI3_Init();
  MX_SPI4_Init();
  MX_SPI5_Init();
  MX_USB_DEVICE_Init();
  MX_UART4_Init();
  MX_ADC1_Init();
  MX_I2C1_Init();
  MX_SDMMC2_SD_Init();
  MX_USART1_UART_Init();
  MX_RTC_Init();
  MX_FATFS_Init();
  MX_TIM2_Init();
  /* USER CODE BEGIN 2 */

  /* Console first: everything below logs through it. Output goes to CDC when
     enumerated and to USART1 while SHEPPARD_CONSOLE_UART_MIRROR is set. */
  console_init();
  console_register(g_main_cmds, (uint8_t)(sizeof g_main_cmds / sizeof g_main_cmds[0]));

  /* Reads the boot state the loader left in the backup registers and starts
     the healthy-boot timer. Requires MX_RTC_Init() to have run. */
  boot_ctrl_init();

  /* Registers the `fw` command. Must follow console_init(). */
  fw_init();

  /* 1 us timebase. Must follow MX_TIM2_Init(). Every sample timestamp and
     every f_measured figure comes from here. */
  if (timebase_init() != 0) {
    console_printf("timebase: TIM2 failed to start\r\n");
  }

  /* SPI transport. Must follow the MX_SPIx_Init() calls and MX_DMA_Init().
     Deasserts every chip select, which the legacy code below also does --
     harmless duplication until the old helpers are retired. */
  bus_init();

  /* Registers the `icm` and `fifo` commands, and `m1`. */
  icm_console_init();
  validate_console_init();
  storage_console_init();

  /* Registers `ls`, `get` and `rm`. The board has no removable card reader, so
     this is the only route from the instrument to analysis. */
  xfer_console_init();

  /* Status indication for unattended runs. Must follow MX_GPIO_Init() and
     timebase_init(). */
  led_init();

  /* Registers `seq`. */
  seq_console_init();

  HAL_Delay(500);
  HAL_GPIO_WritePin(LED_1_GPIO_Port, LED_1_Pin, GPIO_PIN_RESET);
  HAL_GPIO_WritePin(LED_2_GPIO_Port, LED_2_Pin, GPIO_PIN_RESET);
  HAL_GPIO_WritePin(LED_3_GPIO_Port, LED_3_Pin, GPIO_PIN_RESET);
  HAL_GPIO_WritePin(LED_4_GPIO_Port, LED_4_Pin, GPIO_PIN_RESET);
  HAL_Delay(500);



  HAL_Delay(50);                               /* let sensors finish power-on reset */
  for (int i = 0; i < 4; i++)
    HAL_GPIO_WritePin(g_buses[i].cs_port, g_buses[i].cs_pin, GPIO_PIN_SET);

  /* Give the host a bounded chance to enumerate and open the port before the
     boot report goes out. Data sent before the port is opened is discarded
     (TN-16 SS7.2), and this is the one report that is not repeatable on
     demand -- everything in it except fs_test() is, via `scan` and `sd`.
     Falls through immediately when nothing is attached. */
  for (uint32_t t0 = HAL_GetTick();
       !console_cdc_ready() && (HAL_GetTick() - t0) < 2500U; )
  {
    HAL_Delay(10);
  }

  /* ---- boot self-test: runs once, then never again ---------------------- */
  print_banner();
  scan_all_buses();                                 /* identify all four     */
  for (int i = 0; i < 4; i++) sensor_configure(&g_buses[i]);
  for (int i = 0; i < 4; i++) sensor_mvp_log(&g_buses[i], i);   /* one sample */

  rtc_init_once();
  rtc_print();

  fs_test();

  console_printf("boot self-test done. `help` for commands.\r\n");

  /* Battery boot with an armed plan runs the campaign now. Returns immediately
     when VBUS is present, so plugging in to offload data can never start one.
     Placed after the self-test so the sensors are configured and the card is
     known good before anything unattended begins. */
  seq_autorun_if_armed();
  /* USER CODE END 2 */

  /* Infinite loop */
  /* USER CODE BEGIN WHILE */
  while (1)
  {

    /* USER CODE END WHILE */

    /* USER CODE BEGIN 3 */

      /* The loop does housekeeping and nothing else. Everything that used to
         print on a timer -- bus rescan, sample dump, USB state, data-ready
         rate -- is now on demand via `scan`, `usb` and `rate`. Unsolicited
         console traffic corrupts a firmware transfer, makes captured logs
         unparseable, and puts SPI activity on the bus at moments nobody
         asked for, which is not what you want on a noise measurement. */
      console_task();          /* assemble input lines, dispatch commands    */
      fw_task();               /* image verify / erase / reprogram / reset   */
      rate_task();             /* finish an armed data-ready measurement     */
      usbd_composite_task();   /* deliver a pending DFU_DETACH out of the ISR */
      boot_ctrl_task();        /* healthy-boot latch, and the deferred reset  */
      led_task();              /* status indication, non-blocking            */
  }
  /* USER CODE END 3 */
}

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
/* USER CODE BEGIN 4 */



/* ST / InvenSense style: addr|0x80 = read, one dummy byte clocks out the data */
static uint8_t spi_read8(const bus_t *b, uint8_t reg)
{
  uint8_t tx[2] = { (uint8_t)(reg | 0x80U), 0x00U };
  uint8_t rx[2] = { 0 };
  HAL_GPIO_WritePin(b->cs_port, b->cs_pin, GPIO_PIN_RESET);
  HAL_SPI_TransmitReceive(b->hspi, tx, rx, 2, SPI_TMO);
  HAL_GPIO_WritePin(b->cs_port, b->cs_pin, GPIO_PIN_SET);
  return rx[1];
}

/* BMI323: 16-bit regs; on SPI a read returns 1 dummy byte, then LSB, MSB */
static uint8_t bmi323_chipid(const bus_t *b)
{
  uint8_t tx[4] = { (uint8_t)(0x00U | 0x80U), 0, 0, 0 };  /* CHIP_ID @ 0x00 */
  uint8_t rx[4] = { 0 };
  HAL_GPIO_WritePin(b->cs_port, b->cs_pin, GPIO_PIN_RESET);
  HAL_SPI_TransmitReceive(b->hspi, tx, rx, 4, SPI_TMO);
  HAL_GPIO_WritePin(b->cs_port, b->cs_pin, GPIO_PIN_SET);
  return rx[2];                              /* rx[1]=dummy, rx[2]=id LSB, rx[3]=MSB */
}

/* Try every IMU your board may carry; 1 if any valid WHO_AM_I answers.
   Order matters: ICM/ISM are checked first so the BMI323 path only runs
   on a bus that is neither, avoiding cross-talk false positives.        */
static int bus_present(const bus_t *b)
{
  if (spi_read8(b, 0x75) == 0x47) return 1;  /* ICM-42688-P */
  if (spi_read8(b, 0x0F) == 0x6B) return 1;  /* ISM330DHCX  */
  (void)bmi323_chipid(b);                    /* 1st read latches BMI323 into SPI */
  if (bmi323_chipid(b) == 0x43) return 1;    /* BMI323 */
  return 0;
}




/* Kept as a thin shim so the ~60 existing call sites did not all have to
   change in one edit. New code should call console_printf() directly; this
   name will go away during the module split.

   Output now reaches CDC and, while SHEPPARD_CONSOLE_UART_MIRROR is set,
   USART1 as well. Safe to call before console_init(): console_write() checks
   both sinks itself. Still blocking, still not for a hot data path, still
   never from an ISR. */
static void uart_log(const char *fmt, ...)
{
  va_list ap;
  va_start(ap, fmt);
  console_vprintf(fmt, ap);
  va_end(ap);
}

static void print_banner(void)
{
  uart_log("\r\n==================== Sheppard bring-up ====================\r\n");
  uart_log("Build: %s %s\r\n", __DATE__, __TIME__);
  uart_log("SYSCLK=%lu Hz  HCLK=%lu Hz  PCLK1=%lu Hz  PCLK2=%lu Hz\r\n",
            (unsigned long)HAL_RCC_GetSysClockFreq(),
            (unsigned long)HAL_RCC_GetHCLKFreq(),
            (unsigned long)HAL_RCC_GetPCLK1Freq(),
            (unsigned long)HAL_RCC_GetPCLK2Freq());
  uart_log("=============================================================\r\n");
}

/* Raw register dump — no interpretation, just bytes. Only called on a bus
   that failed every known WHO_AM_I match, to see if it's truly dead
   (constant 0x00 / 0xFF) or answering something unexpected (a real but
   unrecognised chip, an address-offset bug, or a noisy/floating line). */
static void hexdump_bus(const bus_t *b, uint8_t start_reg, uint8_t count)
{
  char line[96];
  int pos = snprintf(line, sizeof line, "    regs 0x%02X..0x%02X:",
                      start_reg, (uint8_t)(start_reg + count - 1));
  for (uint8_t i = 0; i < count; i++) {
    if (pos >= (int)sizeof line - 4) break;          /* clamp */
    uint8_t v = spi_read8(b, (uint8_t)(start_reg + i));
    pos += snprintf(line + pos, sizeof(line) - (size_t)pos, " %02X", v);
  }
  pos += snprintf(line + pos, sizeof(line) - pos, "\r\n");
  HAL_UART_Transmit(&huart1, (uint8_t*)line, pos, 100);
}

static void scan_all_buses(void)
{
	static const char *names[4] = { "bus1(SPI1/ICM)", "bus2(SPI3/ICM)",
	                                "bus3(SPI5/ISM)", "bus4(SPI4/BMI)" };
  uint32_t t = HAL_GetTick();

  uart_log("--- scan @ t=%lu ms ---\r\n", (unsigned long)t);

  for (int i = 0; i < 4; i++) {
    const bus_t *b = &g_buses[i];
    uint8_t icm = spi_read8(b, 0x75);
    uint8_t ism = spi_read8(b, 0x0F);
    uint8_t bmi = bmi323_chipid(b);
    int present = bus_present(b);

    const char *ident = "NONE";
    if (icm == 0x47)      ident = "ICM-42688-P";
    else if (ism == 0x6B) ident = "ISM330DHCX";
    else if (bmi == 0x43) ident = "BMI323";

    uart_log("%-11s ICM=0x%02X ISM=0x%02X BMI=0x%02X  -> %s%s\r\n",
              names[i], icm, ism, bmi, ident,
              present ? "" : "  [DEAD/UNKNOWN]");

    HAL_GPIO_WritePin(b->led_port, b->led_pin, present ? LED_ON : LED_OFF);

    if (!present) hexdump_bus(b, 0x00, DUMP_REGS);   /* extra detail only when needed */
  }
}





static void icm_write8(const bus_t *b, uint8_t reg, uint8_t val)
{
  uint8_t tx[2] = { (uint8_t)(reg & 0x7FU), val };   /* bit7=0 -> write */
  HAL_GPIO_WritePin(b->cs_port, b->cs_pin, GPIO_PIN_RESET);
  HAL_SPI_Transmit(b->hspi, tx, 2, SPI_TMO);
  HAL_GPIO_WritePin(b->cs_port, b->cs_pin, GPIO_PIN_SET);
}

/* One CS assertion for the whole burst -- proves multi-byte reads work,
   not just single-register WHO_AM_I. */
static void icm_burst_read(const bus_t *b, uint8_t reg, uint8_t *dst, uint8_t n)
{
  uint8_t tx[1 + 14] = {0};
  uint8_t rx[1 + 14] = {0};
  tx[0] = (uint8_t)(reg | 0x80U);
  HAL_GPIO_WritePin(b->cs_port, b->cs_pin, GPIO_PIN_RESET);
  HAL_SPI_TransmitReceive(b->hspi, tx, rx, (uint16_t)(n + 1), SPI_TMO);
  HAL_GPIO_WritePin(b->cs_port, b->cs_pin, GPIO_PIN_SET);
  for (uint8_t i = 0; i < n; i++) dst[i] = rx[i + 1];
}
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

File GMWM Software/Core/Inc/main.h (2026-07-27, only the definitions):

#define SCK_4_Pin GPIO_PIN_2
#define SCK_4_GPIO_Port GPIOE
#define INT4_1_Pin GPIO_PIN_3
#define INT4_1_GPIO_Port GPIOE
#define INT4_1_EXTI_IRQn EXTI3_IRQn
#define MISO_4_Pin GPIO_PIN_5
#define MISO_4_GPIO_Port GPIOE
#define MOSI_4_Pin GPIO_PIN_6
#define MOSI_4_GPIO_Port GPIOE
#define LSE_IN_Pin GPIO_PIN_14
#define LSE_IN_GPIO_Port GPIOC
#define LSE_OUT_Pin GPIO_PIN_15
#define LSE_OUT_GPIO_Port GPIOC
#define INT3_1_Pin GPIO_PIN_5
#define INT3_1_GPIO_Port GPIOF
#define INT3_1_EXTI_IRQn EXTI9_5_IRQn
#define SCK_3_Pin GPIO_PIN_7
#define SCK_3_GPIO_Port GPIOF
#define MISO_3_Pin GPIO_PIN_8
#define MISO_3_GPIO_Port GPIOF
#define MOSI_3_Pin GPIO_PIN_9
#define MOSI_3_GPIO_Port GPIOF
#define CS_3_Pin GPIO_PIN_10
#define CS_3_GPIO_Port GPIOF
#define HSE_IN_Pin GPIO_PIN_0
#define HSE_IN_GPIO_Port GPIOH
#define HSE_OUT_Pin GPIO_PIN_1
#define HSE_OUT_GPIO_Port GPIOH
#define TX_1_Pin GPIO_PIN_0
#define TX_1_GPIO_Port GPIOA
#define RX_1_Pin GPIO_PIN_1
#define RX_1_GPIO_Port GPIOA
#define CS_1_Pin GPIO_PIN_4
#define CS_1_GPIO_Port GPIOA
#define SCK_1_Pin GPIO_PIN_5
#define SCK_1_GPIO_Port GPIOA
#define MISO_1_Pin GPIO_PIN_6
#define MISO_1_GPIO_Port GPIOA
#define MOSI_1_Pin GPIO_PIN_7
#define MOSI_1_GPIO_Port GPIOA
#define MOSI_2_Pin GPIO_PIN_2
#define MOSI_2_GPIO_Port GPIOB
#define CS_4_Pin GPIO_PIN_7
#define CS_4_GPIO_Port GPIOE
#define LED_1_Pin GPIO_PIN_12
#define LED_1_GPIO_Port GPIOE
#define LED_2_Pin GPIO_PIN_13
#define LED_2_GPIO_Port GPIOE
#define LED_3_Pin GPIO_PIN_14
#define LED_3_GPIO_Port GPIOE
#define LED_4_Pin GPIO_PIN_15
#define LED_4_GPIO_Port GPIOE
#define VBUS_Pin GPIO_PIN_13
#define VBUS_GPIO_Port GPIOB
#define USB_D__Pin GPIO_PIN_14
#define USB_D__GPIO_Port GPIOB
#define USB_D_B15_Pin GPIO_PIN_15
#define USB_D_B15_GPIO_Port GPIOB
#define INT1_1_Pin GPIO_PIN_8
#define INT1_1_GPIO_Port GPIOA
#define INT1_1_EXTI_IRQn EXTI9_5_IRQn
#define TX_2_Pin GPIO_PIN_9
#define TX_2_GPIO_Port GPIOA
#define RX_2_Pin GPIO_PIN_10
#define RX_2_GPIO_Port GPIOA
#define SWDIO_Pin GPIO_PIN_13
#define SWDIO_GPIO_Port GPIOA
#define SWCLK_Pin GPIO_PIN_14
#define SWCLK_GPIO_Port GPIOA
#define SCK_2_Pin GPIO_PIN_10
#define SCK_2_GPIO_Port GPIOC
#define MISO_2_Pin GPIO_PIN_11
#define MISO_2_GPIO_Port GPIOC
#define INT2_1_Pin GPIO_PIN_12
#define INT2_1_GPIO_Port GPIOC
#define INT2_1_EXTI_IRQn EXTI15_10_IRQn
#define CS_2_Pin GPIO_PIN_1
#define CS_2_GPIO_Port GPIOD
#define CLK_SD_Pin GPIO_PIN_6
#define CLK_SD_GPIO_Port GPIOD
#define CMD_Pin GPIO_PIN_7
#define CMD_GPIO_Port GPIOD
#define DAT0_Pin GPIO_PIN_9
#define DAT0_GPIO_Port GPIOG
#define DAT1_Pin GPIO_PIN_10
#define DAT1_GPIO_Port GPIOG
#define DAT2_Pin GPIO_PIN_11
#define DAT2_GPIO_Port GPIOG
#define DAT3_Pin GPIO_PIN_12
#define DAT3_GPIO_Port GPIOG
#define SCL_Pin GPIO_PIN_6
#define SCL_GPIO_Port GPIOB
#define SDA_Pin GPIO_PIN_7
#define SDA_GPIO_Port GPIOB
#define CD_Pin GPIO_PIN_0
#define CD_GPIO_Port GPIOE

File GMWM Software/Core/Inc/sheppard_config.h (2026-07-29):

/**
  ******************************************************************************
  * @file    sheppard_config.h
  * @brief   Single point of build configuration for the Sheppard firmware.
  *
  * Every compile-time switch that changes measured behaviour lives here, so
  * that one file fully describes the build that produced a dataset. Anything
  * tagged SCIENCE below must be recorded in the record header (TN-16 SS10.5)
  * and frozen across a campaign (TN-16 SS2.1: the clock rate is a science
  * parameter; TN-16 open item 20: -O0 vs -O2 affects SPI timing).
  *
  * This file is NOT generated by CubeMX and will survive regeneration.
  ******************************************************************************
  */

#ifndef SHEPPARD_CONFIG_H
#define SHEPPARD_CONFIG_H

#ifdef __cplusplus
extern "C" {
#endif

/* ==========================================================================
 * Firmware identity
 * ========================================================================== */

#define SHEPPARD_FW_NAME            "sheppard"
#define SHEPPARD_FW_VERSION_MAJOR   0
#define SHEPPARD_FW_VERSION_MINOR   2
#define SHEPPARD_FW_VERSION_PATCH   17
#define SHEPPARD_FW_VERSION_STR     "0.2.17"

/* OPTIMISATION LEVEL IS A SCIENCE PARAMETER -- TN-16 open item 20.
 * Frozen at -Os from 28 July 2026, tag Stage-B-chained-dma-Os onwards. All
 * bring-up data before this (V0.4, M1, the drift runs) was taken at -O0.
 * The original concern was SPI timing; with the transfers now driven by DMA
 * that is hardware-determined rather than code-determined, and what remains
 * is ISR latency (a fixed, calibratable offset) and bus duty cycle, which
 * rule R8 already controls as a confound. Do not change it again mid-campaign
 * -- doing so splits the dataset. */
#define SHEPPARD_OPT_LEVEL          "-Os"

/* Free-text build tag. Change this when the build differs in any way that
   could touch the data, and log it in every record header. */
#define SHEPPARD_BUILD_TAG          "Stage-D-charger-autorun-Os"

/* Directory holding records on the card. One definition, used by both the
   writer and the download commands. */
#define SHEPPARD_SD_DIR             "SHEPPARD"

/* SPI SCK frequency, forced identically on every slot by bus_init().
   THIS IS A SCIENCE PARAMETER. Rule R8 (TN-14 section 6) controls bus activity
   as a confound, so the two specimens must be read over identical buses; before
   28 July slot 2 ran at 16 MHz against slot 1's 8 MHz because SPI3 sits on APB1
   with a different CubeMX prescaler, which would have written a bus-rate
   difference straight into the specimen axis. The ICM-42688-P permits 24 MHz
   (DS-000347 section 10.2); 8 MHz is chosen low to limit switching noise, in
   the same spirit as the 32 MHz SYSCLK. */
#define SHEPPARD_SPI_HZ             8000000UL

/* LED drive polarity. 1 = the pin sinks the cathode, so RESET lights the LED.
   If the indicators come out inverted after flashing -- breathing when they
   should be dark, dark while recording -- flip this and nothing else. */
#define SHEPPARD_LED_ACTIVE_LOW     0

/* ==========================================================================
 * Flash layout
 *
 * STAGE 1 (this build): application linked at the reset vector, flashed by
 *   ST-LINK. No bootloader present. SHEPPARD_APP_BASE must equal
 *   ORIGIN(FLASH) in STM32F723ZETX_FLASH.ld.
 *
 * STAGE 2 (after the DFU loader exists): set SHEPPARD_APP_BASE to 0x08010000,
 *   change ORIGIN(FLASH) in the linker script to match, and leave
 *   SHEPPARD_VTOR_RELOCATE at 1. Nothing else in the application changes.
 *
 * [verify] The 0x08010000 boundary assumes the STM32F723ZE 512 KiB flash is
 * organised 4 x 16 KiB, 1 x 64 KiB, 3 x 128 KiB, making 0x08010000 the start
 * of sector 4. CONFIRM AGAINST RM0431 TABLE "Flash module organization"
 * BEFORE BUILDING THE LOADER -- the loader's sector-erase table depends on
 * the same numbers, and an over-erase takes the loader out with it.
 * ========================================================================== */

#define SHEPPARD_APP_BASE           0x08000000UL
#define SHEPPARD_VTOR_RELOCATE      1     /* harmless when APP_BASE is 0x08000000 */

/* ==========================================================================
 * Console
 *
 * CDC is the primary console. USART1 (PA9/PA10) is a compile-time mirror.
 *
 * NOTE ON THE DEFAULT: you asked for the UART mirror to be opt-in. It ships
 * ENABLED because TN-16 SS3.1 and SS7.3 both depend on it -- USART1 is the only
 * channel that produces output before enumeration, when a charge-only cable
 * is fitted, or when the USB stack itself is the fault. Set it to 0 for
 * science builds, where TN-16 SS7.4 requires USB disconnected anyway and the
 * extra GPIO switching is unwanted.
 * ========================================================================== */

#define SHEPPARD_CONSOLE_CDC            1
#define SHEPPARD_CONSOLE_UART_MIRROR    1     /* -> 0 for science builds */
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

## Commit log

2026-07-27 Sheppard: bring-up firmware, USB self-flasher, host tools
    [Connectors_PWR.kicad_sch, DataLogging.kicad_sch, DataTransmission.kicad_sch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]
2026-07-28 Stage A: timebase, SPI/DMA bus layer, ICM hi-res FIFO driver; V0.4 and M1 answered
2026-07-28 Stage B: arena, record format, storage ring, FIFO sampler; V0.4 and M1 answered; overnight drift build v0.2.3
    [fwupdate.c, main.c, record.c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]
2026-07-28 fw 0.2.7: defer SPI DMA chain to PendSV; abort-on-failed-start; TN-19 s5
    [bus.c, imu_icm42688.c, main.c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]
2026-07-28 fw 0.2.8: fix dead chain condition, watchdog underflow, stolen chain flag; add FIFO overflow + yield reporting
    [record.c, sampler.c, sheppard_config.h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]
2026-07-28 fw 0.2.9: fix partial-block CRC ordering and f_measured reference; add sdat.py reader
    [sdat.py, sheppard_config.h, storage.c]
2026-07-28 console: dataset browser with binary capture in the reader thread; fw 0.2.12 SPI clock matching; analyse.py R4 screen
2026-07-28 fw 0.2.13: recover swallowed watermark pulses; rec AAF+delay; status LEDs; live R2 gate
2026-07-28 fw 0.2.14: boot without USB when VBUS absent; VBUS in header; LED polarity switch; GUI analysis buttons
2026-07-29 Paper skeleton and numbers generator; TN-21..23; transfer-rule figures; tree cleanup
    [summary.csv]
2026-08-02 TN-24: third reference correction (eta +1/64); slot-2 replication; software dither sweep closes the rho-ODR confound; step size shown ODR-dependent; methods reordered; phase directive removed
    [summary.csv]
2026-08-02 TN-25: Bussgang gain derived, added to analyse.py, measured (E_phi[G]=1 at 0.9 sigma); corpus audit; full-length example paper
    [summary.csv]
2026-09-20 Untrack internal notes, manuscript and generated figures
    [summary.csv]

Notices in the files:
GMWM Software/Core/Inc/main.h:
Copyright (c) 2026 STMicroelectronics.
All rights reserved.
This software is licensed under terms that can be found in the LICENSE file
